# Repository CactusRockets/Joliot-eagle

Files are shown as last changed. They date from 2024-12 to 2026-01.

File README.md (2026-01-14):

# Avionics Boards for the Joliot Rocket

This repository contains the design files for the avionics boards used in the **Joliot rocket** developed by **Cactus Rockets Design**.

### Description

The avionics system is composed of the following boards:

* **Processing Board**
* **Actuation Board**
* **Battery Board**

The **Processing Board** is responsible for handling sensor data, data logging, and telemetry transmission.

The **Actuation Board** contains the circuitry required for the correct activation of the *Skib* (the recovery deployment mechanism).

The **Battery Board** distributes the battery voltages to connectors so they can be easily used by the other boards.

*Note:* All board files can be opened using **Autodesk Eagle**.

### Schematics and Layouts

Processing Board:




Actuation Board:




Battery Board:




### Operation

The Processing Board includes a system-activation switch. Once the switch is pressed, the system powers on and begins reading all onboard modules. After each reading, the data is stored on a microSD card and transmitted via telemetry.

When the Processing Board detects a fall event, it sends a signal to the Actuation Board, which then activates the *Skib* to deploy the drogue recovery system.

Na queda do foguete com apenas o paraquedas drogue liberado, no momento que o foguete tiver abaixo de 500m de altitude, o sistema deve detectar isso e ativar o outro skib que aciona o sistema de recuperação principal do foguete, liberando assim o paraquedas main. Fazendo assim que o foguete tenha um voo e recuperação estável até o chão.

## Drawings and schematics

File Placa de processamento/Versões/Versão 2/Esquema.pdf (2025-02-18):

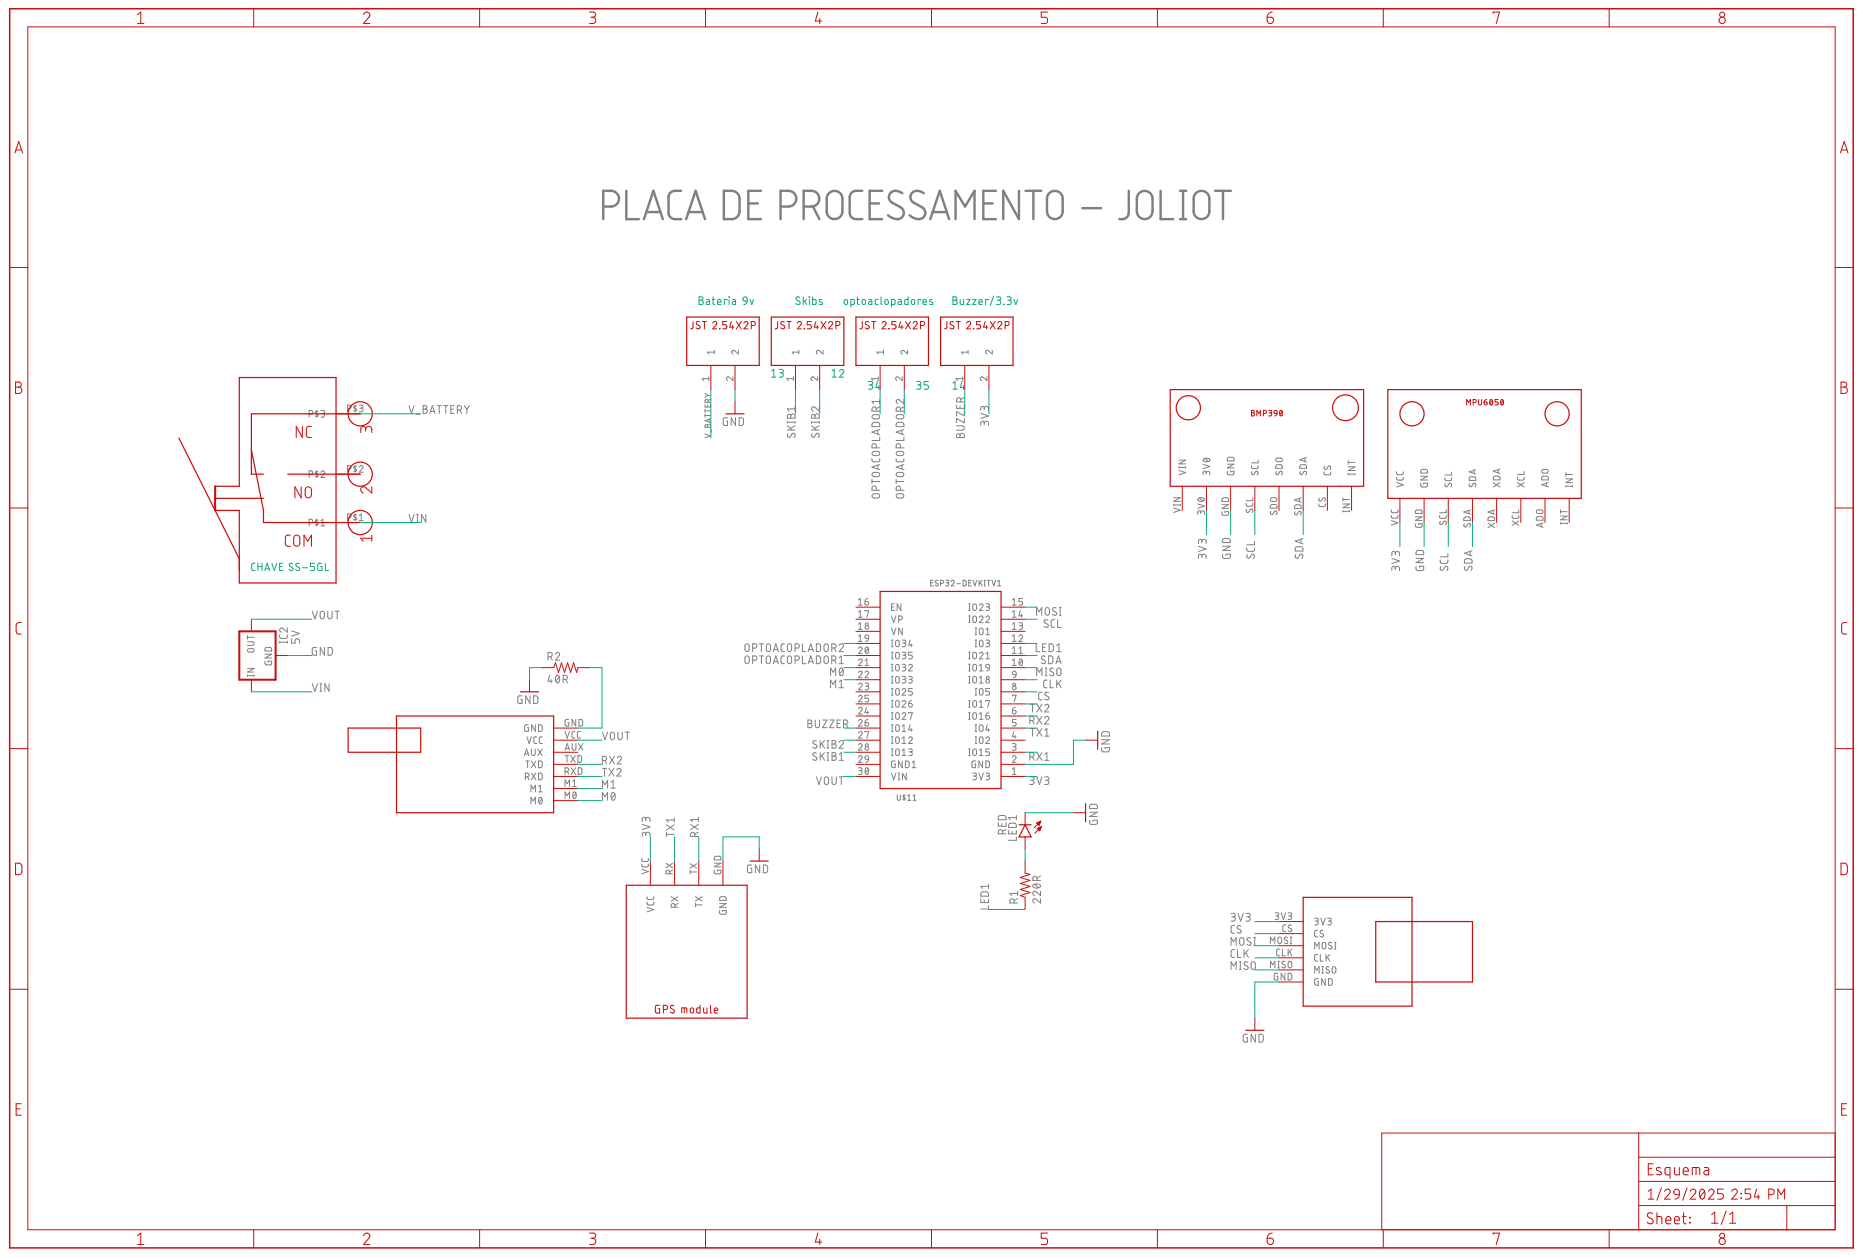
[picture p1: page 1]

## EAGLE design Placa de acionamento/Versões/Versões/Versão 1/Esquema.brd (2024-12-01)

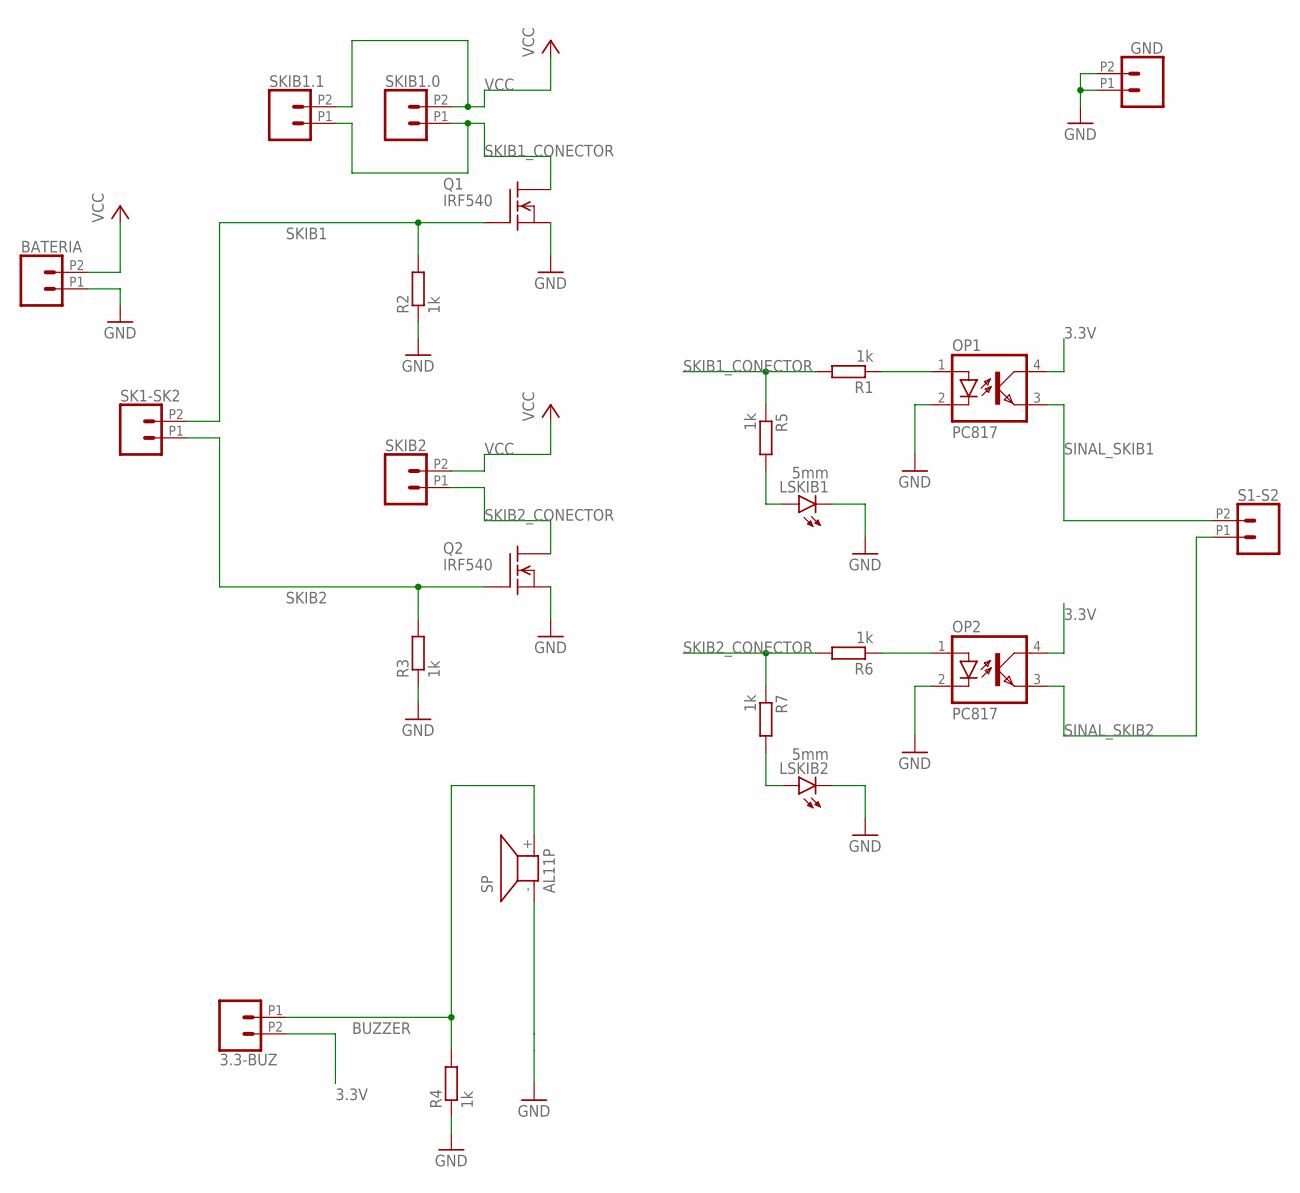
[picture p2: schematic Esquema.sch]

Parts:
3.3-BUZ: CONN_022.54MM_SCREWTERM; 1X02_2.54_SCREWTERM
BATERIA: CONN_022.54MM_SCREWTERM; 1X02_2.54_SCREWTERM
GND: CONN_022.54MM_SCREWTERM; 1X02_2.54_SCREWTERM
LSKIB1, LSKIB2: 5mm; LED5MM
OP1, OP2: PC817; DIL04
Q1, Q2: IRF540; TO220
R1, R2, R3, R4, R5, R6, R7: 1k; 0207/10
S1-S2: CONN_022.54MM_SCREWTERM; 1X02_2.54_SCREWTERM
SK1-SK2: CONN_022.54MM_SCREWTERM; 1X02_2.54_SCREWTERM
SKIB1.0, SKIB1.1, SKIB2: CONN_022.54MM_SCREWTERM; 1X02_2.54_SCREWTERM
SP: AL11P

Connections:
3.3V: 3.3-BUZ.P2 (2), OP1.4 (COL), OP2.4 (COL)
BUZZER: 3.3-BUZ.P1 (1), R4.2, SP.+ (2)
GND: BATERIA.P1 (1), GND.P1 (1), GND.P2 (2), LSKIB1.K (C), LSKIB2.K (C), OP1.2 (C), OP2.2 (C), Q1.3 (S), Q2.3 (S), R2.1, R3.1, R4.1, SP.- (1)
unnamed: LSKIB2.A, R7.2
unnamed: LSKIB1.A, R5.2
unnamed: OP1.1 (A), R1.1
unnamed: OP2.1 (A), R6.1
SINAL_SKIB1: OP1.3 (EMIT), S1-S2.P2 (2)
SINAL_SKIB2: OP2.3 (EMIT), S1-S2.P1 (1)
SKIB1: Q1.1 (G), R2.2, SK1-SK2.P2 (2)
SKIB1_CONECTOR: Q1.2 (D), R1.2, R5.1, SKIB1.0.P1 (1), SKIB1.1.P1 (1)
SKIB2: Q2.1 (G), R3.2, SK1-SK2.P1 (1)
SKIB2_CONECTOR: Q2.2 (D), R6.2, R7.1, SKIB2.P1 (1)
VCC: BATERIA.P2 (2), SKIB1.0.P2 (2), SKIB1.1.P2 (2), SKIB2.P2 (2)

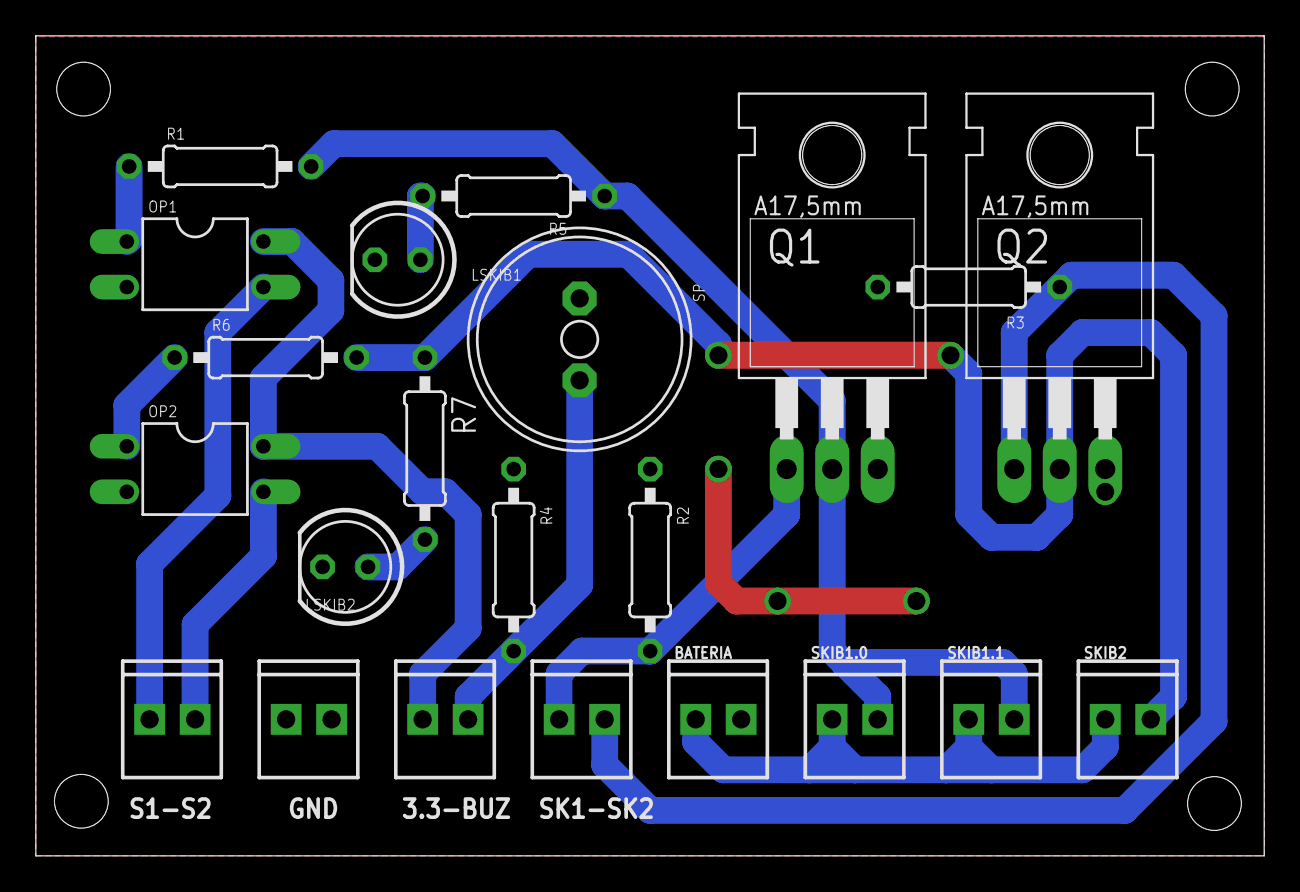
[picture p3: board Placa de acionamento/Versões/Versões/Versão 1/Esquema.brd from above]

Board: 2 copper layers, 68.6 x 45.8 mm, 22 parts (0 on the bottom side), 14 nets.

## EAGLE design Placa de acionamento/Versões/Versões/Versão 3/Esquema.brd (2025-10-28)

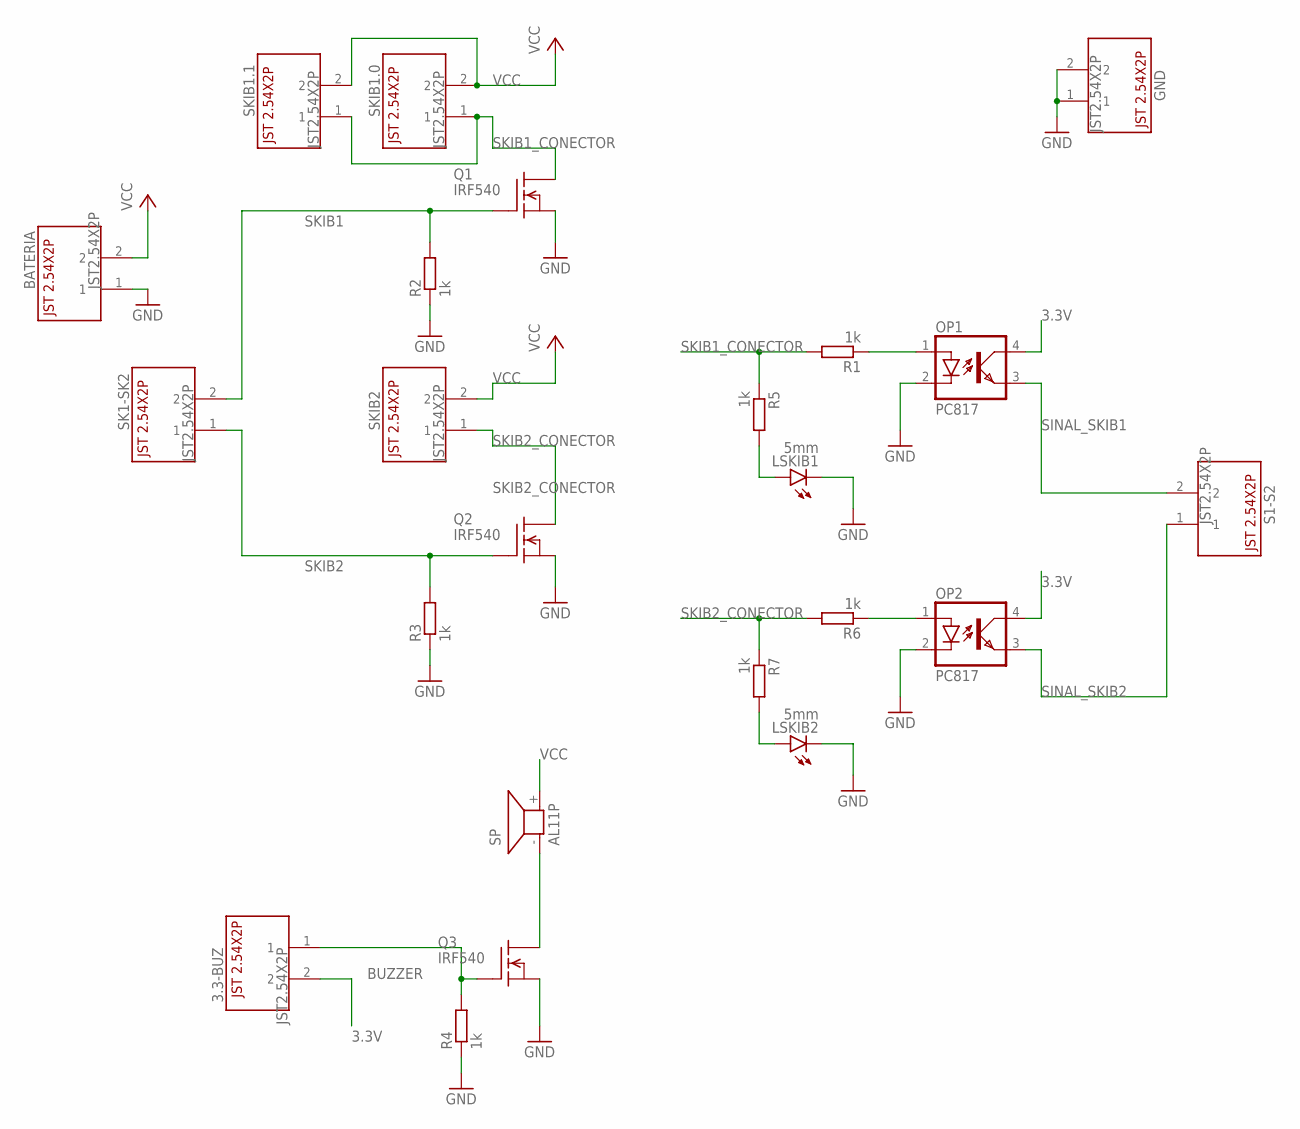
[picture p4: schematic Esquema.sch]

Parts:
3.3-BUZ: JST2.54X2P; JST2.54X2P_FOOTPRINT
BATERIA: JST2.54X2P; JST2.54X2P_FOOTPRINT
GND: JST2.54X2P; JST2.54X2P_FOOTPRINT
LSKIB1, LSKIB2: 5mm; LED5MM
OP1, OP2: PC817; DIL04
Q1, Q2, Q3: IRF540; TO220
R1, R2, R3, R4, R5, R6, R7: 1k; 0207/10
S1-S2: JST2.54X2P; JST2.54X2P_FOOTPRINT
SK1-SK2: JST2.54X2P; JST2.54X2P_FOOTPRINT
SKIB1.0, SKIB1.1, SKIB2: JST2.54X2P; JST2.54X2P_FOOTPRINT
SP: AL11P

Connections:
3.3V: 3.3-BUZ.2, OP1.4 (COL), OP2.4 (COL)
BUZZER: 3.3-BUZ.1, Q3.1 (G), R4.2
GND: BATERIA.1, GND.1, GND.2, LSKIB1.K (C), LSKIB2.K (C), OP1.2 (C), OP2.2 (C), Q1.3 (S), Q2.3 (S), Q3.3 (S), R2.1, R3.1, R4.1
unnamed: LSKIB2.A, R7.2
unnamed: Q3.2 (D), SP.- (1)
unnamed: LSKIB1.A, R5.2
unnamed: OP1.1 (A), R1.1
unnamed: OP2.1 (A), R6.1
SINAL_SKIB1: OP1.3 (EMIT), S1-S2.2
SINAL_SKIB2: OP2.3 (EMIT), S1-S2.1
SKIB1: Q1.1 (G), R2.2, SK1-SK2.2
SKIB1_CONECTOR: Q1.2 (D), R1.2, R5.1, SKIB1.0.1, SKIB1.1.1
SKIB2: Q2.1 (G), R3.2, SK1-SK2.1
SKIB2_CONECTOR: Q2.2 (D), R6.2, R7.1, SKIB2.1
VCC: BATERIA.2, SKIB1.0.2, SKIB1.1.2, SKIB2.2, SP.+ (2)

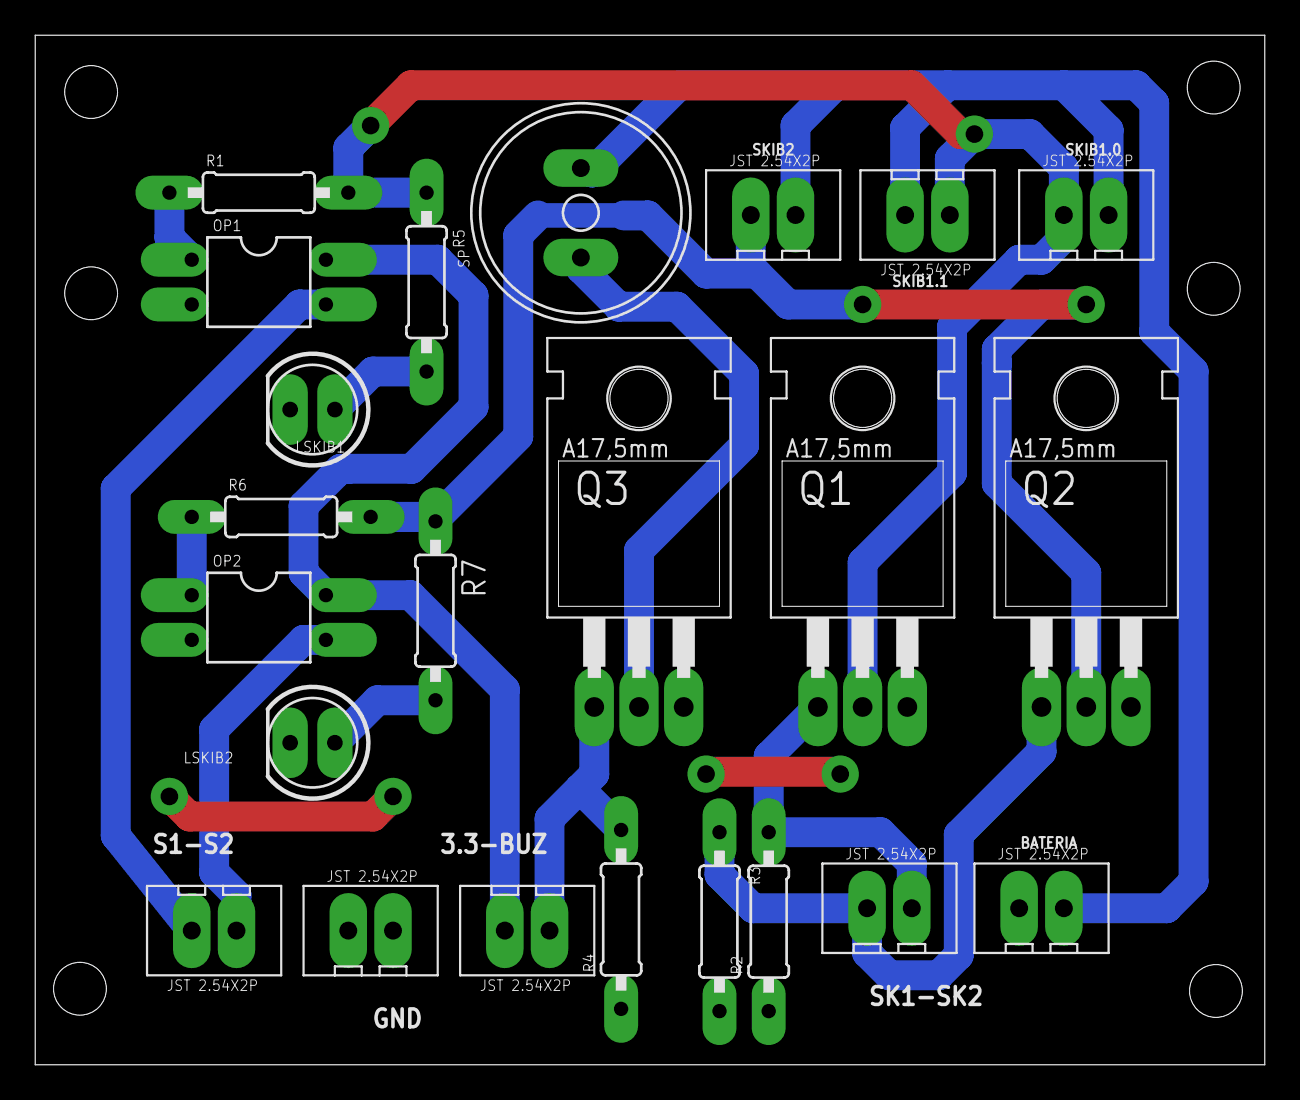
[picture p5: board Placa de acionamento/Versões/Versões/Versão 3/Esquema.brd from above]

Board: 2 copper layers, 69.8 x 58.5 mm, 23 parts (0 on the bottom side), 15 nets.

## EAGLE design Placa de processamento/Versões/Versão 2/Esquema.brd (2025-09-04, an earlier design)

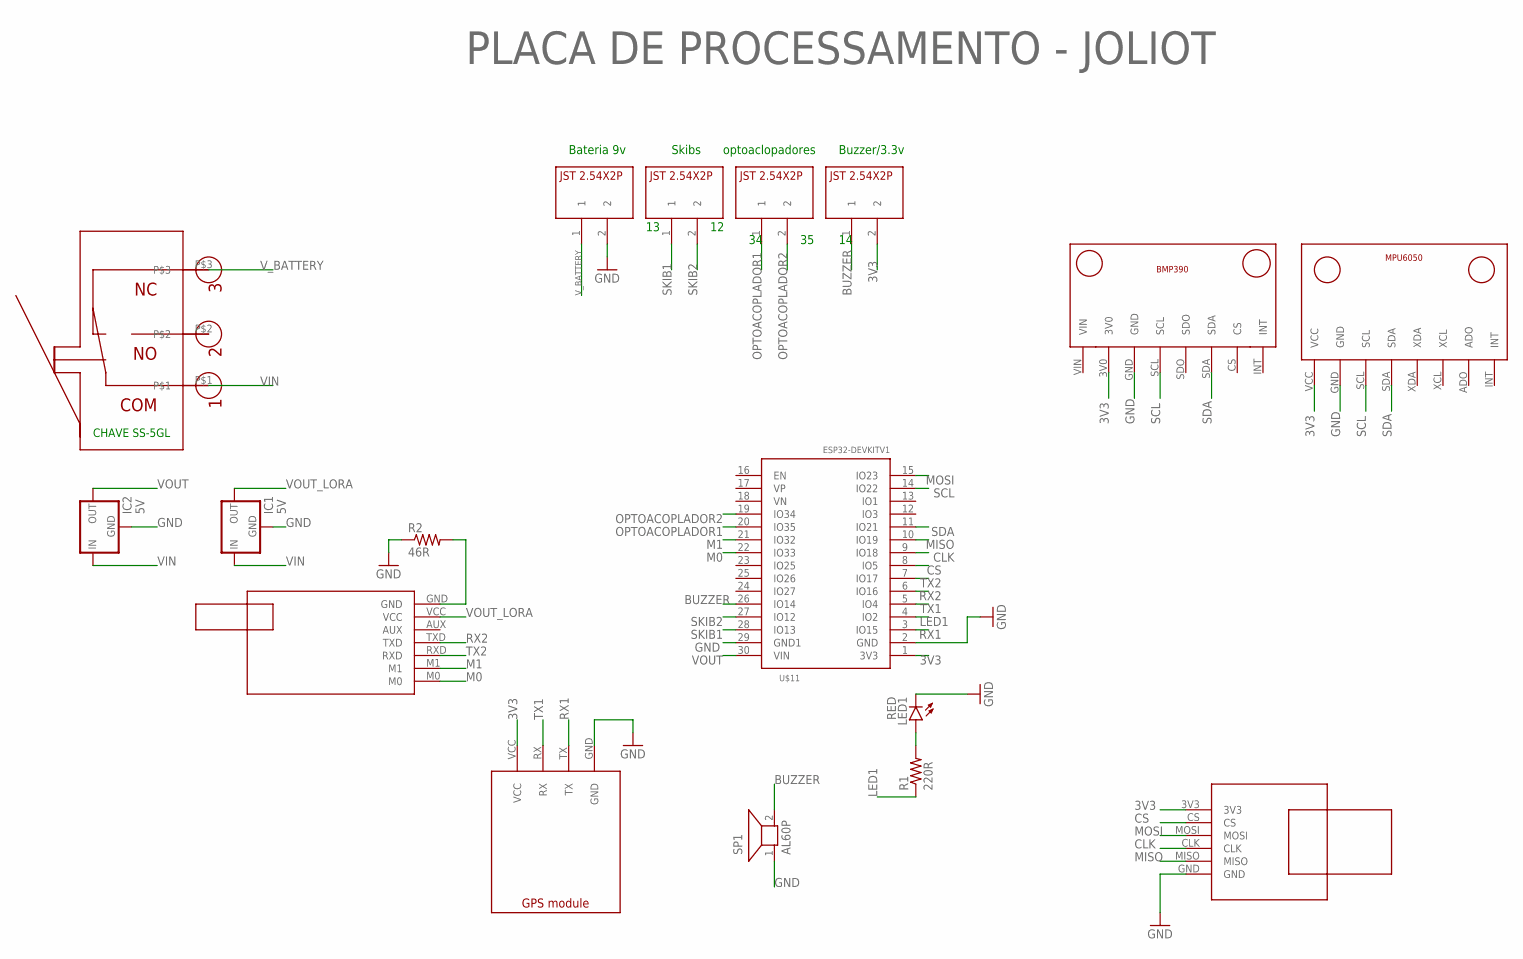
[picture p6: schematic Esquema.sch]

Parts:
IC1, IC2: 5V; 78XXL
LED1: RED; LED5MM
R1: 220R; 0309/12
R2: 46R; 0309/12
SP1: AL60P
U$1: BMP390V1; BMP390_FOOTPRINT
U$2: E22-400T30D; E22-400T30D_FOOTPRINT
U$3: GPS_MODULE; GPS_MODULE_FOOTPRINT
U$4, U$5, U$6, U$7: JST2.54X2P; JST2.54X2P_FOOTPRINT
U$8: MICROSD_SMALL_READER; MICROSD_SMALL_READER_FOOTPRINT
U$9: MPU6050V1; MPU6050_FOOTPRINT
U$11: ESP32DEVKITV1; ESP32-DEVKITV1
U$12: CHAVE_SS-5GL; CHAVESS-5GL

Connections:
3V3: U$1.3V0, U$3.VCC, U$4.2, U$8.3V3, U$9.VCC, U$11.1 (3V3)
BUZZER: SP1.2, U$4.1, U$11.26 (IO14)
CLK: U$8.CLK, U$11.9 (IO18)
CS: U$8.CS, U$11.8 (IO5)
GND: IC1.GND, IC2.GND, LED1.K (C), R2.1, SP1.1, U$1.GND, U$3.GND, U$7.2, U$8.GND, U$9.GND, U$11.2 (GND), U$11.29 (GND1)
LED1: R1.1, U$11.4 (IO2)
M0: U$2.M0, U$11.22 (IO33)
M1: U$2.M1, U$11.21 (IO32)
MISO: U$8.MISO, U$11.10 (IO19)
MOSI: U$8.MOSI, U$11.15 (IO23)
unnamed: LED1.A, R1.2
unnamed: R2.2, U$2.GND
OPTOACOPLADOR1: U$5.1, U$11.20 (IO35)
OPTOACOPLADOR2: U$5.2, U$11.19 (IO34)
RX1: U$3.TX, U$11.3 (IO15)
RX2: U$2.TXD, U$11.6 (IO16)
SCL: U$1.SCL, U$9.SCL, U$11.14 (IO22)
SDA: U$1.SDA, U$9.SDA, U$11.11 (IO21)
SKIB1: U$6.1, U$11.28 (IO13)
SKIB2: U$6.2, U$11.27 (IO12)
TX1: U$3.RX, U$11.5 (IO4)
TX2: U$2.RXD, U$11.7 (IO17)
VIN: IC1.IN, IC2.IN, U$12.P$1
VOUT: IC2.OUT, U$11.30 (VIN)
VOUT_LORA: IC1.OUT, U$2.VCC
V_BATTERY: U$7.1, U$12.P$3

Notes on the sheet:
Bateria 9v
Skibs
optoaclopadores
Buzzer/3.3v
PLACA DE PROCESSAMENTO - JOLIOT

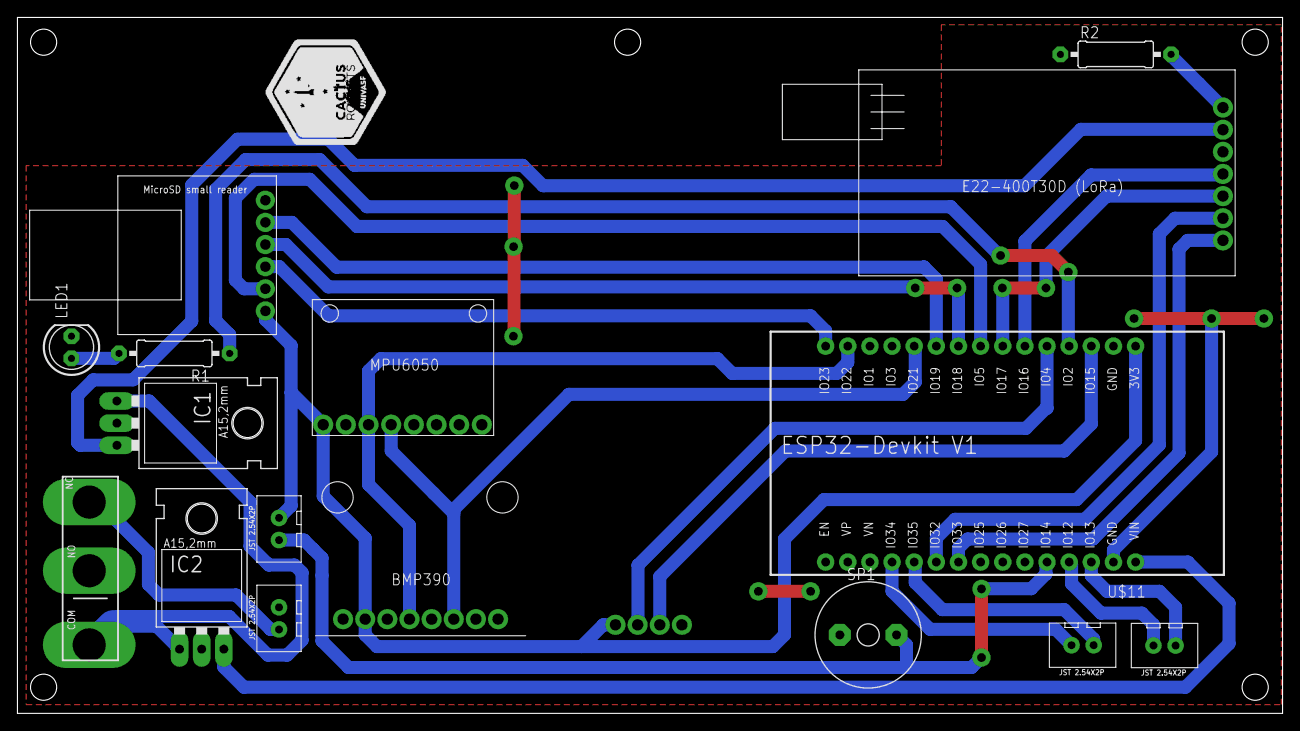
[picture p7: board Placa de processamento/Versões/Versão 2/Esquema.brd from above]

Board: 2 copper layers, 145.1 x 79.8 mm, 17 parts (1 on the bottom side), 26 nets.

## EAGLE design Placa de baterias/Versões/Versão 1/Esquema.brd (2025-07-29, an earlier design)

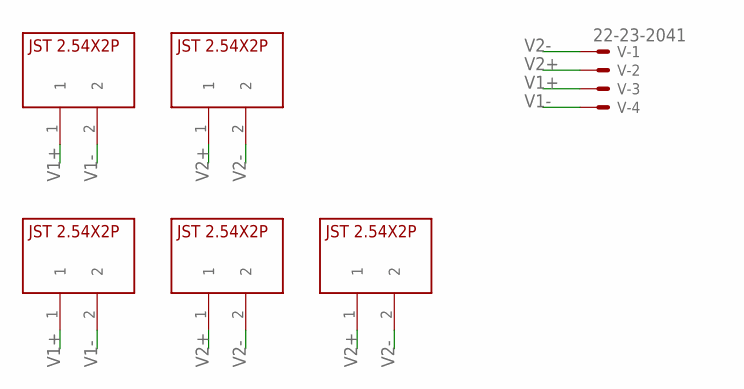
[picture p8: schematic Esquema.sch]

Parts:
U$1, U$2, U$3, U$4, U$5: JST2.54X2P; JST2.54X2P_FOOTPRINT
V: 22-23-2041

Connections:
V1+: U$1.1, U$4.1, V.3
V1-: U$1.2, U$4.2, V.4
V2+: U$2.1, U$3.1, U$5.1, V.2
V2-: U$2.2, U$3.2, U$5.2, V.1

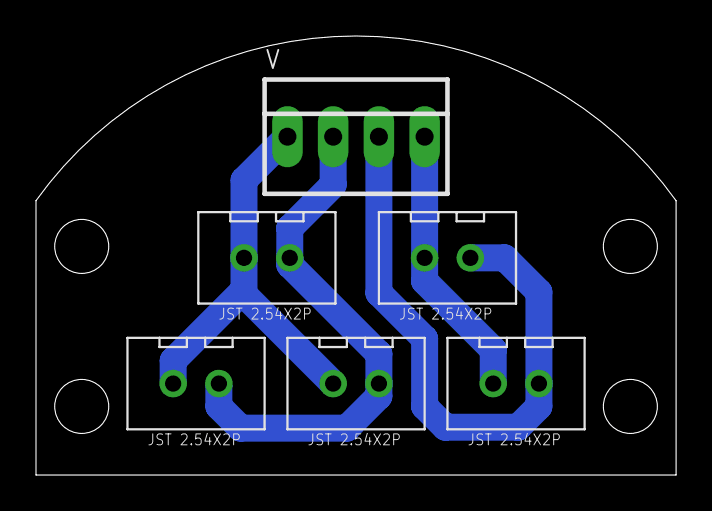
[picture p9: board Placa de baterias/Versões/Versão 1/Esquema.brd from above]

Board: 2 copper layers, 35.6 x 24.4 mm, 6 parts (0 on the bottom side), 4 nets.

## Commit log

2024-04-18 Criado projeto 'Placa de acionamento'
    [Esquema.brd, Esquema.sch]
2024-04-18 Adicionado conexão LoRa
    [Esquema.brd, Esquema.sch]
2024-04-19 Ligado MPU ao ESP32
    [Esquema.brd, Esquema.sch]
2024-04-19 Adicionado quase totas as conexões, falta aquelas relacionadas à alimentação (conectores JST)
    [Esquema.brd, Esquema.sch]
2024-04-20 Placa de acionamento
    [Esquema 01 guilherme.brd, Esquema 01 guilherme.sch, Esquema 02 guilherme.brd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]
2024-04-20 Upload para o Fusion
    [Esquema 02 guilherme.brd]
2024-04-21 Update de roteamento
    [Esquema.brd, Esquema.sch]
2024-04-21 Roteamento da placa
    [Esquema.brd, Esquema.sch]
2024-04-21 Componentes de biblioteca atualizados
    [Esquema.brd, Esquema.sch]
2024-04-22 Ajuste nas conexões e trilhas
    [Esquema 03 guilherme.brd]
2024-04-22 Ajustes em trilhas, adicionado furos, ajustado dimensões
    [Esquema.brd]
2024-04-22 Ajuste de trilhas, furos e posicionamento.
    [Esquema.brd]
2024-04-22 Ajustes na PCB finalizados!
    [Esquema.brd, Esquema.sch]
2024-04-22 Finalizados os ajustes na placa de acionamento do Joliot.
    [Esquema 03 guilherme.brd]
2024-04-22 Ajustes finalizados!
    [Esquema.brd, Esquema.sch]
2024-04-23 Adicionado plano de terra no top - Joliot processamento.
    [Esquema.brd]
2024-04-23 Atualização
    [Esquema.brd, Esquema.sch]
2024-04-23 Adicionado LED indicativo.
    [Esquema.brd, Esquema.sch]
2024-11-06 placa de baterias
    [Esquema.brd, Esquema.sch]
2024-11-19 Adiciona Placa de processamento ao repositório
    [Esquema.brd, Esquema.sch]
2025-02-18 mudanças na placa de processamento
    [Esquema.brd, Esquema.sch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]
2025-07-01 atualização placa de baterias
    [Esquema.brd, Esquema.sch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]
2025-08-26 atualização de regulador
    [Esquema.brd, Esquema.sch]
2025-08-30 FEAT: Regulador de tensão do LoRa adicionado
    [Esquema.brd, Esquema.sch]
2025-09-01 CHORE: adicionando modelos 3D
    [Esquema.brd, Esquema.sch]
2025-09-01 resolved erros in pcb layout
    [Esquema.brd]
2025-09-01 uptate boards
    [Esquema.brd, Esquema.sch]
2025-09-01 resolved layout position
    [Esquema.brd, Esquema.sch]
2025-09-02 CHORE: atualizando modelos 3D
    [Esquema.brd]
2025-09-04 update position
    [Esquema.brd]

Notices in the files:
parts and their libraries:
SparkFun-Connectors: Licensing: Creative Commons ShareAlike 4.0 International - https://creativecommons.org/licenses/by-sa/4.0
